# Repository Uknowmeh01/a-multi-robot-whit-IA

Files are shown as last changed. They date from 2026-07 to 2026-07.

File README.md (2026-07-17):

# AI Robot Rover 



A modular, 3D-printable indoor robot rover built around a Raspberry Pi 4 and an ESP32.

The project combines a parametric mechanical chassis, motor control, environmental sensors, a camera, autonomous behaviors, and a local web interface for controlling the robot from a phone or computer.

> [!IMPORTANT]
> The chassis design and software prototype are complete, but the full robot has not yet been physically assembled or tested.

## Project goals

The long-term goal is to build a small indoor assistant robot capable of:

- manual control from a phone;
- autonomous obstacle avoidance;
- camera-based object detection;
- navigation between rooms using visual markers;
- receiving simple voice commands;
- playing sounds or messages through a speaker;
- carrying small objects or messages around the house.

One planned example is telling the robot to go to the living room or to a family member's room. The robot would follow a known route, recognize a visual marker at its destination, stop, and play a notification sound.

## Hardware architecture

The robot uses two main computers:

### Raspberry Pi 4

The Raspberry Pi handles high-level functions:

- camera processing;
- object detection;
- web server and control interface;
- navigation logic;
- communication with the ESP32;
- future voice recognition and audio playback.

### ESP32

The ESP32 handles real-time hardware control:

- four DC motors;
- two TB6612FNG motor drivers;
- ultrasonic distance sensors;
- LEDs;
- environmental sensors;
- emergency stopping;
- serial communication with the Raspberry Pi.

## Planned hardware

- Raspberry Pi 4
- ESP32 development board
- 4 DC geared motors
- 2 TB6612FNG motor drivers
- Raspberry Pi Camera Module 3 Wide
- HC-SR04 ultrasonic sensors
- BH1750 light sensor
- microphone
- LEDs
- battery and power regulation system
- future USB speaker
- 3D-printed mechanical chassis
- M3 screws, nuts, and threaded inserts

Exact motor, battery, and mounting dimensions may still be adjusted to match the purchased hardware.

## Mechanical design

The chassis was designed as a parametric, multi-part KCL project in Zoo Design Studio.

### Main dimensions

| Property | Value |
|---|---:|
| Main deck size | 280 × 200 mm |
| Mechanical stack height | 148 mm |
| Approximate maximum length with angled inserts | 304 mm |
| M3 clearance hole | 3.4 mm |
| Maximum individual print area | 220 × 220 mm |

All individual parts are designed to fit on a standard 220 × 220 mm print bed.

### Mechanical features

- split lower deck for easier printing;
- three alignment tongues between lower-deck sections;
- aligned M3 joint holes;
- removable front and rear panels;
- removable corner brackets;
- reserved mounting areas for motors, battery, and motor drivers;
- cable-routing openings;
- separate sensor and camera inserts;
- modular upper electronics plate;
- removable top cover;
- editable shared parameters;
- exploded and inspection assemblies.

The current model intentionally contains only mechanical geometry and empty mounting provisions. Electronics, motors, wheels, batteries, cameras, sensors, and cables are not modeled as solid components.

## CAD files

The main CAD files include:

```text
cad/
├── main.kcl
├── explodedView.kcl
├── lowerDeckAssembly.kcl
├── parameters.kcl
├── chassisDimensions.md
├── removableCornerBracket.kcl
└── printable-parts/
```

The exact directory structure may differ depending on how the exported Zoo project is organized.

### Main CAD documents

- `main.kcl` contains the complete assembled chassis.
- `explodedView.kcl` contains the exploded assembly.
- `lowerDeckAssembly.kcl` provides a clear view of the split-deck joint.
- `parameters.kcl` contains shared editable dimensions.
- `chassisDimensions.md` documents dimensions, quantities, print envelopes, and export information.

### Printable parts

The project contains separate KCL parts for:

- front lower plate;
- rear lower plate;
- upper electronics plate;
- top cover;
- front sensor panel;
- rear utility panel;
- ultrasonic mounting insert;
- camera mounting insert;
- lower spacer posts;
- upper spacer posts;
- removable corner brackets.

STEP and STL binaries are not currently included because the original design environment exports KCL source files. Each printable part is isolated and ready to be exported from Zoo Design Studio.

## Software

The software is divided between the ESP32 and Raspberry Pi.

```text
software/
├── esp32/
└── raspberry-pi/
```

### ESP32 software

The ESP32 firmware is responsible for:

- motor control;
- serial command parsing;
- ultrasonic sensor measurements;
- lighting control;
- Bluetooth communication;
- autonomous safety behavior.

### Raspberry Pi software

The Raspberry Pi application includes:

- robot control logic;
- camera support;
- object-detection prototype;
- serial communication with the ESP32;
- operating-mode management;
- local web server;
- phone-friendly control interface;
- installation script;
- systemd service;
- tests.

## Web control interface

The Raspberry Pi hosts a local control website.

The interface is intended to provide:

- movement controls;
- speed adjustment;
- operating-mode selection;
- emergency stop;
- sensor information;
- connection status;
- AI detection information.

When the robot is connected to the same Wi-Fi network as a phone or computer, the interface can be opened using the Raspberry Pi's local IP address.

Example:

```text
http://192.168.1.42:5000
```

The exact IP address depends on the local network.

## Operating modes

The planned modes include:

### Manual mode

The user controls movement from the web interface or Bluetooth.

### Autonomous mode

The robot uses its distance sensors to move while avoiding obstacles.

### AI vision mode

The Raspberry Pi camera runs an object-detection prototype. The current software may use a person as its default target, but this behavior can be changed.

### Future navigation mode

A future version will use visual markers such as AprilTags or ArUco markers.

Each room or waypoint can have a unique marker. The robot will use these markers to follow routes and recognize when it has reached a destination.

## Current project status

### Completed

- [x] Parametric chassis design
- [x] Separate printable parts
- [x] Main mechanical assembly
- [x] Exploded assembly
- [x] Split lower-deck system
- [x] Removable corner brackets
- [x] Motor and battery reserved zones
- [x] ESP32 firmware prototype
- [x] Raspberry Pi software prototype
- [x] Local web interface prototype
- [x] Installation script and service files

### Not yet completed

- [ ] Print physical chassis parts
- [ ] Purchase and measure final hardware
- [ ] Assemble the complete rover
- [ ] Test motor direction and speed
- [ ] Test battery and power distribution
- [ ] Validate sensor measurements
- [ ] Validate emergency-stop behavior
- [ ] Test the Raspberry Pi and ESP32 protocol
- [ ] Test the web interface on the physical robot
- [ ] Add visual-marker navigation
- [ ] Add voice commands
- [ ] Add speaker notifications
- [ ] Document real-world test results

## Safety

Initial motor tests should be performed with the wheels raised off the ground.

Before autonomous testing:

- verify the emergency stop;
- use a low movement speed;
- keep cables away from wheels;
- securely mount the battery;
- add suitable power protection and a fuse;
- test in an open indoor area;
- keep the robot away from stairs and fragile objects.

## Repository structure

A possible repository layout is:

```text
AI-Robot-Rover/
├── README.md
├── LICENSE
├── .gitignore
├── docs/
│   └── images/
│       └── chassis-final.png
├── cad/
│   ├── main.kcl
│   ├── explodedView.kcl
│   ├── lowerDeckAssembly.kcl
│   ├── parameters.kcl
│   └── chassisDimensions.md
└── software/
    ├── esp32/
    └── raspberry-pi/
```

## Development notes

Some parts of the initial CAD and software were created with assistance from AI development tools.

All generated work will be reviewed, adapted, physically tested, and documented during the construction process. A generated design passing software validation does not guarantee that every mechanical tolerance or hardware integration detail will work correctly on the first physical build.

## Future ideas

- indoor room-to-room navigation;
- voice activation;
- destination markers;
- speaker announcements;
- automatic charging station;
- motor encoders;
- IMU-assisted movement;
- battery monitoring;
- removable payload platform;
- improved camera mount;
- physical emergency-stop button.

## License

A license has not yet been selected.

Before other people reuse the project, an open-source license such as the MIT License, Apache-2.0, or CERN Open Hardware Licence should be added.

## Author

Created by **Uknowmeh01** as a personal robotics and engineering project.

Built for learning, experimenting, and sharing with the Hack Club community.

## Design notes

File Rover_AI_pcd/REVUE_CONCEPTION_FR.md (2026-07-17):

# Revue de conception et guide de production

## 1. Dimensionnement électrique

Hypothèse de départ : quatre moteurs 6 V, environ 1 A chacun en régime et jusqu'à 3 A au blocage. Le moteur représente ~4 A moyens et 12 A transitoires sur VBAT. Le Raspberry Pi 4 et ses périphériques USB peuvent demander 4 A sur 5 V ; ESP32, capteurs et LED ajoutent environ 0,8 A. À 7,4 V et 90 % de rendement, la charge 5 V/4,8 A demande environ 3,6 A à la batterie. Le courant moyen de pack peut donc approcher 7,6 A, avec des pointes supérieures à 15 A.

Recommandations : pack 2S avec BMS ≥20 A, câbles batterie AWG16, interrupteur et arrêt d'urgence ≥20 A DC, F1 15 A à temporisation adaptée, buck 5 V/9 A. Si les essais au blocage dépassent la capacité des TB6612, ne pas augmenter simplement le fusible : changer les drivers.

## 2. Mesure batterie

L'INA226 est retenu plutôt que l'INA219 : meilleure résolution, plage de bus jusqu'à 36 V, temps de conversion configurable et meilleure marge pour les transitoires. Avec 5 mΩ, 15 A donnent 75 mV et 1,125 W ; le shunt 3 W garde une marge thermique. La calibration logicielle doit utiliser la valeur réellement mesurée du shunt.

## 3. Adaptation HC-SR04

Chaque ECHO passe par 10 kΩ en série puis 20 kΩ vers la masse, soit environ 3,33 V pour une sortie 5 V. Pour une liaison unidirectionnelle lente, ce pont est plus simple et plus robuste qu'un convertisseur bidirectionnel à MOSFET. Les résistances doivent rester près de l'ESP32. TRIG est directement en 3,3 V ; les HC-SR04 usuels le reconnaissent. Si une variante ne le reconnaît pas, ajouter un buffer AHCT.

## 4. Commande des moteurs

Deux 74HC595 génèrent les huit directions et les LED d'état ; les quatre PWM restent directement reliés aux timers ESP32. Au démarrage, maintenir MOTOR_STBY bas, charger les registres, verrouiller les sorties puis seulement activer STBY. Les TB6612FNG intègrent les diodes de roue libre ; des diodes externes ne sont pas nécessaires. C7/C9 et C8/C10 doivent être au plus près des broches VCC/VM, C2 près de la zone puissance, et un 100 nF doit être soudé aux bornes de chaque moteur.

## 5. Implantation et routage

- Carte 4 couches : F.Cu signaux/puissance, In1 signaux horizontaux, In2 signaux verticaux/retours courts, B.Cu plan GND continu.
- Zone forte intensité à gauche, logique au centre, Raspberry Pi et connecteurs capteurs à droite.
- Garder au moins 20 mm entre boucles moteurs/buck et connecteurs capteurs.
- Largeurs après calcul IPC et validation fabricant : batterie/VMOTOR 4 mm sur cuivre externe 2 oz ou polygone équivalent ; chaque moteur ≥2 mm ; 5 V principal ≥2,5 mm ; logique 0,25 mm ; vias puissance multiples 0,4 mm finis minimum.
- Réunir les retours moteur au plan près de C2 et du shunt ; ne pas créer une coupure étroite sous ESP32/INA226.
- Les pistes de mesure IN+/IN− doivent être Kelvin jusqu'aux pads internes du shunt et éloignées des sorties moteur.

Le PCB fourni contient un pré-routage en grille et deux plans GND. Avant fabrication, inspecter les croisements, retoucher les pistes de puissance en polygones, ajouter les vias de couture et relancer le DRC avec les règles du fabricant.

## 6. Fabrication JLCPCB / PCBWay

- 4 couches, FR-4 TG150, 1,6 mm, cuivre externe 2 oz et interne 1 oz.
- Finition ENIG recommandée pour le shunt et les petits boîtiers ; HASL sans plomb acceptable pour un prototype manuel.
- Espacement/piste logique ≥0,20 mm, idéal 0,25 mm.
- Via fini 0,40 mm / diamètre 0,80 mm ; trous connecteurs 0,9 à 1,3 mm selon pièce ; montage 2,7 mm pour vis M2.5.
- Masque épargne des deux côtés, sérigraphie blanche, contrôle d'impédance inutile.
- Commander d'abord 5 cartes, assembler une seule carte et terminer les essais avant le lot.

## 7. Assemblage

1. Contrôler PCB nu à l'ohmmètre : aucune continuité VBAT/GND, 5V/GND ou 3V3/GND.
2. Monter passifs, INA226, 74HC595, AP2112 et TB6612 ; inspecter les ponts sous loupe.
3. Monter protections et buck, sans Raspberry Pi, ESP32, capteurs ni moteurs.
4. Mettre une alimentation de laboratoire à 7,4 V, limite 100 mA ; vérifier polarité et absence d'échauffement.
5. Régler/vérifier le buck à 5,10 V. Vérifier 3,3 V.
6. Tester l'I2C et les registres avec l'ESP32 seul, puis brancher le Pi.
7. Tester un moteur roue levée avec limite de courant, puis quatre moteurs.
8. Tester l'arrêt d'urgence en charge et vérifier que MOTOR_STBY revient bas au redémarrage.

## 8. Procédure de mise sous tension initiale

- Interrupteur ouvert, arrêt d'urgence enclenché, aucun moteur.
- Vérifier résistance vers GND de chaque rail.
- Alimentation de laboratoire 7,4 V limitée à 0,1 A, puis 0,5 A.
- Mesurer VMOTOR, +5V, +5V_RPI, +5V_LOGIC, +3V3 aux TP.
- Contrôler consommation à vide et température pendant 5 minutes.
- Insérer ESP32, charger un firmware minimal avec STBY=0.
- Valider LED, INA226, BH1750 et trois ECHO.
- Insérer le Raspberry Pi éteint, puis augmenter progressivement la limite.

## 9. Checklist de débogage

- Reset ESP32 au démarrage moteur : vérifier chute VBAT, C2, câblage en étoile et masse.
- Pi sous-tension : mesurer +5V_RPI au connecteur J5 sous charge ; viser 5,0–5,1 V sans dépasser 5,25 V.
- Valeur INA226 incorrecte : vérifier routage Kelvin, signe IN+/IN−, valeur du shunt et calibration.
- Distance HC-SR04 erratique : vérifier 5 V, ponts 10k/20k, masse, temporisation et éloignement des pistes PWM.
- Moteur inversé : permuter le bornier ou le mapping logiciel, jamais le shunt.
- LED WS2812 instable : masse commune, buffer AHCT, résistance 330 Ω et condensateur local.

## 10. Améliorations possibles

- Drivers DRV8873 avec mesure de courant et protections intégrées pour moteurs plus puissants.
- Deuxième convertisseur 5 V dédié au Raspberry Pi pour isoler davantage les transitoires.
- Superviseur d'alimentation et arrêt propre du Pi avant coupure batterie.
- Connecteurs verrouillables Micro-Fit pour puissance et JST-GH pour capteurs soumis aux vibrations.
- CAN ou RS-485 pour extensions longues.
- Entrées encodeurs avec filtrage Schmitt et protection ESD.
- Chargeur/BMS intégré uniquement dans une révision séparée, avec étude thermique et conformité batterie.

## 11. Erreurs courantes à éviter

- Utiliser une batterie 3S directement avec des moteurs 6 V sans limitation PWM sûre.
- Choisir les TB6612 sans mesurer le courant de blocage.
- Alimenter le Pi par sa broche 5 V avec un buck mal réglé.
- Relier deux sources 3,3 V ensemble : RPI_3V3 n'est pas relié au +3V3 de la carte.
- Monter plusieurs pull-up I2C en parallèle jusqu'à obtenir une résistance trop faible.
- Faire passer CSI, ECHO ou I2C à côté des sorties moteurs.
- Oublier que le microphone et le haut-parleur USB consomment sur le budget 5 V du Pi.

## 12. Checklist finale de production

- [ ] Courant de blocage moteurs mesuré et compatible.
- [ ] Pinout ESP32 réel comparé au PCB.
- [ ] Empreintes comparées aux datasheets et modèles 1:1 imprimés.
- [ ] ERC sans erreur non justifiée.
- [ ] DRC sans violation non justifiée.
- [ ] Zones remplies, aucun îlot cuivre, vias de couture ajoutés.
- [ ] Pistes Kelvin INA226 vérifiées.
- [ ] Polarités J1, condensateurs, diodes et LED vérifiées.
- [ ] Buck réglé à 5,10 V et testé à 6 A.
- [ ] Test arrêt d'urgence et fusible effectué.
- [ ] Gerbers, perçages, IPC-356, BOM et plan d'assemblage relus.
- [ ] Une carte prototype validée thermiquement avant série.

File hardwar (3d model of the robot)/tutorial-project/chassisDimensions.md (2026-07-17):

# Chassis engineering update

## Added in revision

1. Added editable hardware-fit parameters in `parameters.kcl` for motor reserves, battery reserve/access opening, driver reserves, M3 nut-relief diameter/depth, and corner-bracket geometry.
2. Added `removableCornerBracket.kcl` with four printable removable L-brackets. Brackets include M3 clearance holes and cylindrical nut-relief counterbores for captured hardware access.
3. Added four bracket instances to `main.kcl` for removable front/rear and side panel support.

## Hardware-fit tuning parameters

- Motor reserve: 46 x 36 mm
- Motor hole spacing: 32 x 24 mm
- Battery reserve: 70 x 72 mm
- Battery access opening: 42 x 52 mm
- Driver reserve: 36 x 22 mm
- M3 clearance: 3.4 mm
- Nut-relief diameter/depth: 6.6 / 2.4 mm

These are editable envelope values, not modeled electronic or motor geometry. Tune them against the selected purchased hardware before fabrication.

## Validation

- `main.kcl` mock execution: passed
- Corner-bracket constraint check: passed
- Lint: passed
- Individual printable parts remain separate; no glue-dependent assembly was introduced.

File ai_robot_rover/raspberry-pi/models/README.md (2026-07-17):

# Modèle IA

`install.sh` télécharge automatiquement `efficientdet_lite0.tflite` depuis le stockage public MediaPipe si le fichier est absent. Le modèle INT8 reconnaît les 80 classes COCO listées dans `coco_labels.txt`.

Pour remplacer le modèle, modifiez `MODEL_PATH`, `LABELS_PATH` et, si nécessaire, `AI_CONFIDENCE_THRESHOLD` dans `config.py`. Le détecteur accepte les sorties TFLite usuelles `boxes`, `classes`, `scores` et `count`.

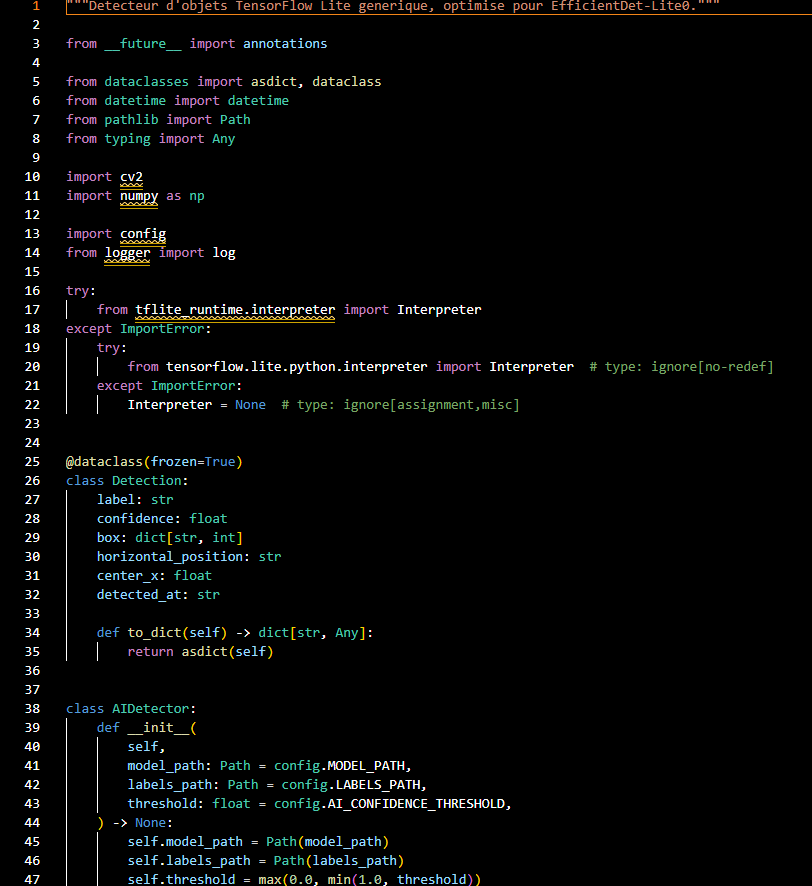
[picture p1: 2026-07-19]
asset/Screenshot 2026-07-17 164706.png

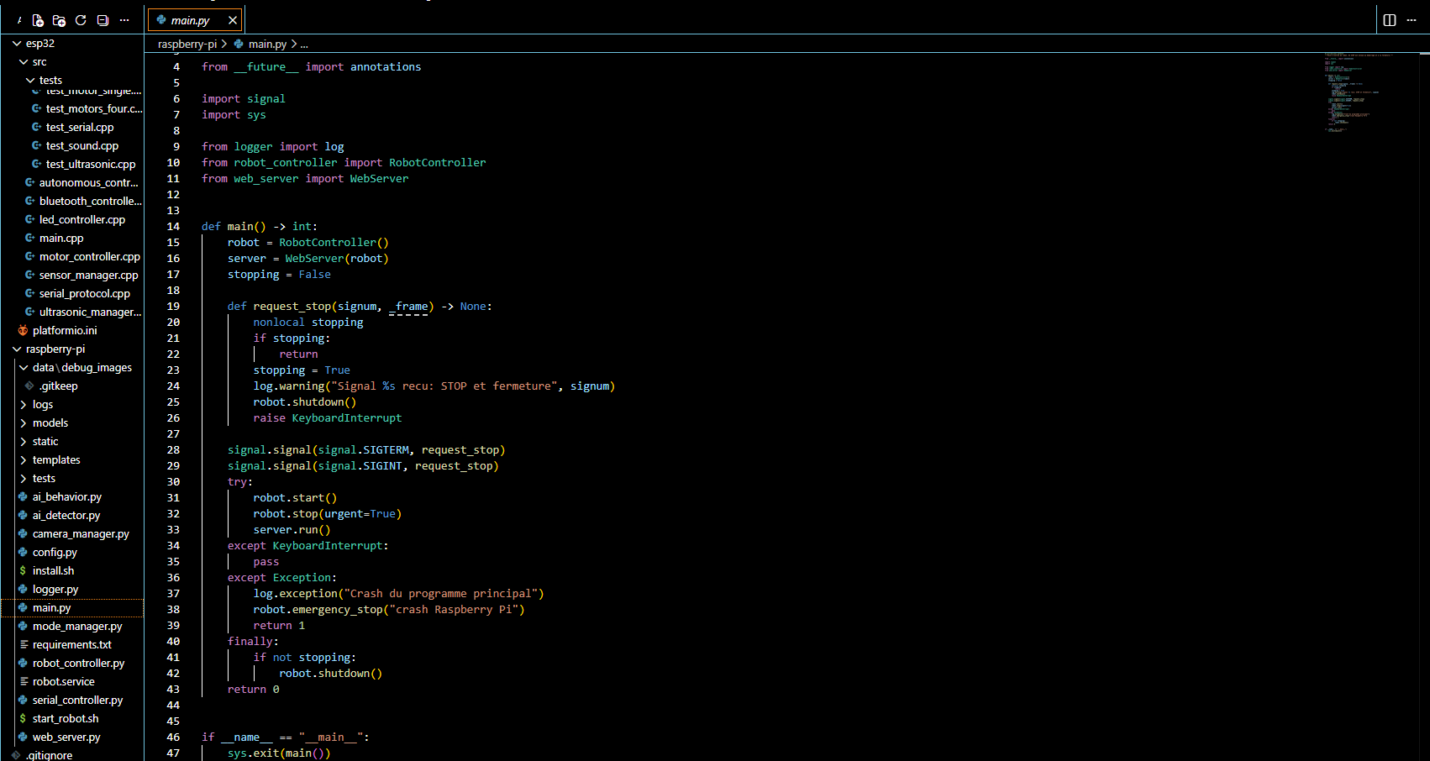
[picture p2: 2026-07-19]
asset/Screenshot 2026-07-19 124222.png

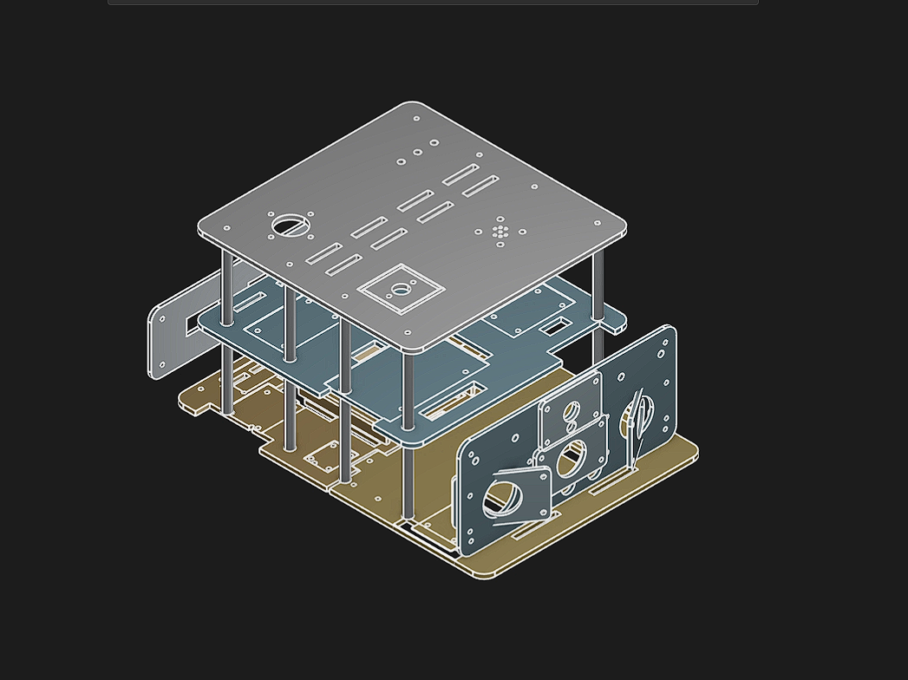
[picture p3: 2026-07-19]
asset/623308507-7109efb7-1d62-4a83-8e4f-e09f7bfac228.png

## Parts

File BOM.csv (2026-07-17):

Category | Item | Quantity | Recommended specification | Priority | Notes
---------- | ------------------------------------------ | -----------: | -------------------------------------------------- | ---------------------- | -------------------------------------------------------
Computing | Raspberry Pi 4 | 1 | 4 GB RAM model | Required | Handles camera, web interface, AI, navigation and audio
Computing | ESP32 development board | 1 | ESP32-WROOM-32 DevKit | Required | Handles motors, sensors, LEDs and real-time control
Computing | MicroSD card | 1 | 32 or 64 GB, A1 or A2 | Required | Raspberry Pi operating system and software
Computing | USB cable | 1 | Compatible with the ESP32 connector | Required | Communication between Raspberry Pi and ESP32
Cooling | Raspberry Pi heatsink kit | 1 | Compatible with Raspberry Pi 4 | Recommended | Helps control temperature
Cooling | Cooling fan | 1 | 30 mm or 40 mm | Recommended | Match the chassis mounting area
Motion | DC geared motors | 4 | Preferably with built-in encoders | Required | Check voltage, current, shaft size and dimensions
Motion | Wheels | 4 | Compatible with motor shafts | Required | Choose suitable diameter and grip
Motion | TB6612FNG motor drivers | 2 | Dual-channel motor driver boards | Required | One board controls two motors
Motion | Motor brackets | 4 | Metal or 3D-printed | Required | Must match the exact motors
Motion | Motor mounting hardware | 1 set | Screws, washers and nuts | Required | Size depends on the motor brackets
Power | Protected battery pack | 1 | Pre-assembled pack with protection/BMS | Required | Do not build a lithium pack from loose cells
Power | Battery charger | 1 | Exact match for battery chemistry and voltage | Required | Must be compatible with the selected battery
Power | Raspberry Pi DC-DC converter | 1 | Stable 5 V output, at least 3 A | Required | Powers the Raspberry Pi safely
Power | Motor DC-DC converter | 1 | Only if motor voltage differs from battery voltage | Conditional | Choose after selecting motors and battery
Power | Main power switch | 1 | Rated for the robot’s maximum current | Required | Must be easily accessible
Power | Emergency-stop button | 1 | Latching type | Strongly recommended | Should immediately disable motor power
Power | Fuse holder | 1 | Inline or panel-mounted | Required | Place close to the battery
Power | Fuses | Several | Value selected after motor current is known | Required | Keep spare fuses
Power | Power distribution board or terminal block | 1 | Rated for total current | Required | Distributes battery power safely
Power | Battery connectors | 1 pair | Polarized, locking connectors | Required | Prevents reversed connections
Power | Battery monitoring sensor | 1 | INA219 or INA226 | Recommended | Measures voltage and current
Sensors | Ultrasonic distance sensors | 3 | HC-SR04 or 3.3 V-compatible equivalent | Required | Front, left and right
Sensors | Logic-level converter | 1 | At least 3 channels | Required with HC-SR04 | Protects ESP32 inputs from 5 V Echo signals
Sensors | Light sensor | 1 | BH1750 | Required | Measures ambient light
Sensors | IMU | 1 | MPU6050, BNO055 or equivalent | Recommended | Helps estimate orientation and movement
Sensors | Motor encoders | 4 | Built into motors if possible | Recommended | Improves navigation accuracy
Sensors | Cliff sensors | 2 to 4 | Infrared downward-facing sensors | Recommended | Helps avoid stairs and drops
Sensors | Limit switches | 2 | Small lever-type switches | Optional | Can detect physical contact
Vision | Raspberry Pi Camera Module 3 Wide | 1 | Wide-angle version | Required for AI vision | Used for object and marker detection
Vision | CSI camera ribbon cable | 1 | Correct length for the chassis | Required | Connects the camera to the Raspberry Pi
Vision | Adjustable camera mount | 1 | 3D-printed | Required | Should allow vertical angle adjustment
Navigation | AprilTags or ArUco markers | Several | Printed on matte paper or card | Future feature | Used for room and waypoint navigation
Audio | USB microphone | 1 | Linux-compatible | Future feature | Simplest option for voice commands
Audio | USB speaker | 1 | Compact, Raspberry Pi-compatible | Future feature | Used for sounds and spoken messages
Audio | Small amplifier and speaker | 1 set | Alternative to USB speaker | Optional | Requires additional wiring
Audio | Buzzer | 1 | 3.3 V or transistor-driven | Recommended | Simple alerts and status sounds
Lighting | Status LEDs | 3 to 5 | Different colors | Recommended | Power, error, mode and connection indicators
Lighting | LED resistors | 1 set | Values matched to selected LEDs | Required with LEDs | Protects LEDs and GPIO pins
Lighting | LED strip or LED ring | 1 | 5 V addressable type | Optional | Visual robot status effects
Wiring | Flexible electrical wire | 1 assortment | Multiple gauges | Required | Thicker wire for motors and battery
Wiring | Dupont jumper wires | 1 set | Male and female assortment | Prototyping only | Avoid for motor or battery power
Wiring | JST connector kit | 1 assortment | Matching crimp terminals and housings | Recommended | Makes wiring removable and tidy
Wiring | Screw terminals | Several | Rated for expected current | Recommended | Useful for motors and power distribution
Wiring | Heat-shrink tubing | 1 assortment | Multiple diameters | Required | Insulates soldered connections
Wiring | Cable ties | 1 pack | Small sizes | Required | Cable management
Wiring | Cable-tie mounts | Several | Adhesive or screw-mounted | Optional | Helps organize the chassis
Wiring | Perfboard or custom distribution PCB | 1 | Suitable size | Recommended | Better than a breadboard for final assembly
Wiring | Breadboard | 1 | Standard solderless board | Prototyping only | Use only during early testing
Wiring | Ferrules | 1 assortment | Match wire sizes | Recommended | Improves screw-terminal connections
Wiring | Electrical tape | 1 roll | Quality insulation tape | Recommended | Supplementary insulation only
Chassis | PETG filament | 1 to 2 kg | 1.75 mm | Required | Better heat and impact resistance than basic PLA
Chassis | M3 screws | 1 assortment | Several lengths | Required | Used throughout the chassis
Chassis | M3 DIN 934 hex nuts | 1 assortment | Standard steel nuts | Required | Compatible with captive nut pockets
Chassis | M3 washers | 1 assortment | Standard flat washers | Recommended | Spreads mechanical load
Chassis | M3 lock nuts | Several | Nylon-insert type | Recommended | Useful in vibrating areas
Chassis | M3 heat-set inserts | 30 to 60 | Match printed pocket dimensions | Recommended | Allows repeated assembly
Chassis | M2.5 or M3 standoffs | 1 set | Plastic or metal | Required | Mounts the Raspberry Pi and electronics
Chassis | Velcro straps | 2 to 3 | Reusable | Required | Battery and cable retention
Chassis | Rubber pads | Several | Small adhesive pads | Optional | Reduces vibration
Chassis | Fan guard | 1 | Match fan size | Recommended | Protects fingers and cables
Tools | Multimeter | 1 | Digital | Required | Essential for electrical testing
Tools | Screwdriver set | 1 | Small electronics sizes | Required | Assembly and maintenance
Tools | Caliper | 1 | Digital or mechanical | Recommended | Checks printed dimensions and hardware fit
Tools | Soldering iron | 1 | Temperature-controlled | Required | Permanent electrical connections
Tools | Soldering-iron stand | 1 | Heat-resistant | Required | Safer soldering
Tools | Desoldering braid or pump | 1 | Standard electronics type | Recommended | Fixes soldering mistakes
Tools | Helping hands | 1 | Adjustable clips | Recommended | Holds wires while soldering
Tools | Wire cutters | 1 | Small electronics type | Required | Cuts wires and leads
Tools | Wire stripper | 1 | Suitable for selected wire gauges | Required | Prepares electrical wires
Tools | JST crimping tool | 1 | Compatible with selected terminals | Recommended | Makes reliable connectors
Tools | Safety glasses | 1 | Impact-resistant | Required | For soldering and assembly
Tools | USB power meter | 1 | USB voltage/current display | Optional | Useful for Raspberry Pi power testing

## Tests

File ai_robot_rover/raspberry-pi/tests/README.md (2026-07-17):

# Programmes de test Raspberry Pi

Exécuter depuis `raspberry-pi` avec l'environnement installé :

```bash
.venv/bin/python tests/test_serial_communication.py
.venv/bin/python tests/test_camera.py
.venv/bin/python tests/test_ai_model.py
.venv/bin/python tests/test_ai_model.py chemin/vers/image.jpg
.venv/bin/python tests/test_web_interface.py
.venv/bin/python tests/test_emergency_stop.py --confirm-wheels-off-ground
```

Le test Web ne déplace aucun moteur. Les tests série commencent et terminent par `STOP`. Ne réarmez jamais un arrêt d'urgence avant d'avoir retiré l'obstacle et identifié sa cause.

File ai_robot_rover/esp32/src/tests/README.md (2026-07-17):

# Tests matériels ESP32

Chaque fichier est un programme PlatformIO indépendant sélectionné par un environnement de `platformio.ini`.

```bash
pio run -e test_motor_single -t upload
pio run -e test_motors_four -t upload
pio run -e test_ultrasonic -t upload
pio run -e test_bh1750 -t upload
pio run -e test_sound -t upload
pio run -e test_leds -t upload
pio run -e test_bluetooth -t upload
pio run -e test_serial -t upload
pio run -e test_emergency -t upload
pio device monitor -b 115200
```

Les tests moteur et arrêt d'urgence exigent le mot `START` sur le moniteur série. Retirer les roues du sol, dégager les câbles, prévoir un interrupteur physique sur l'alimentation moteur et commencer avec `MIN_TEST_SPEED` dans `include/config.h`.

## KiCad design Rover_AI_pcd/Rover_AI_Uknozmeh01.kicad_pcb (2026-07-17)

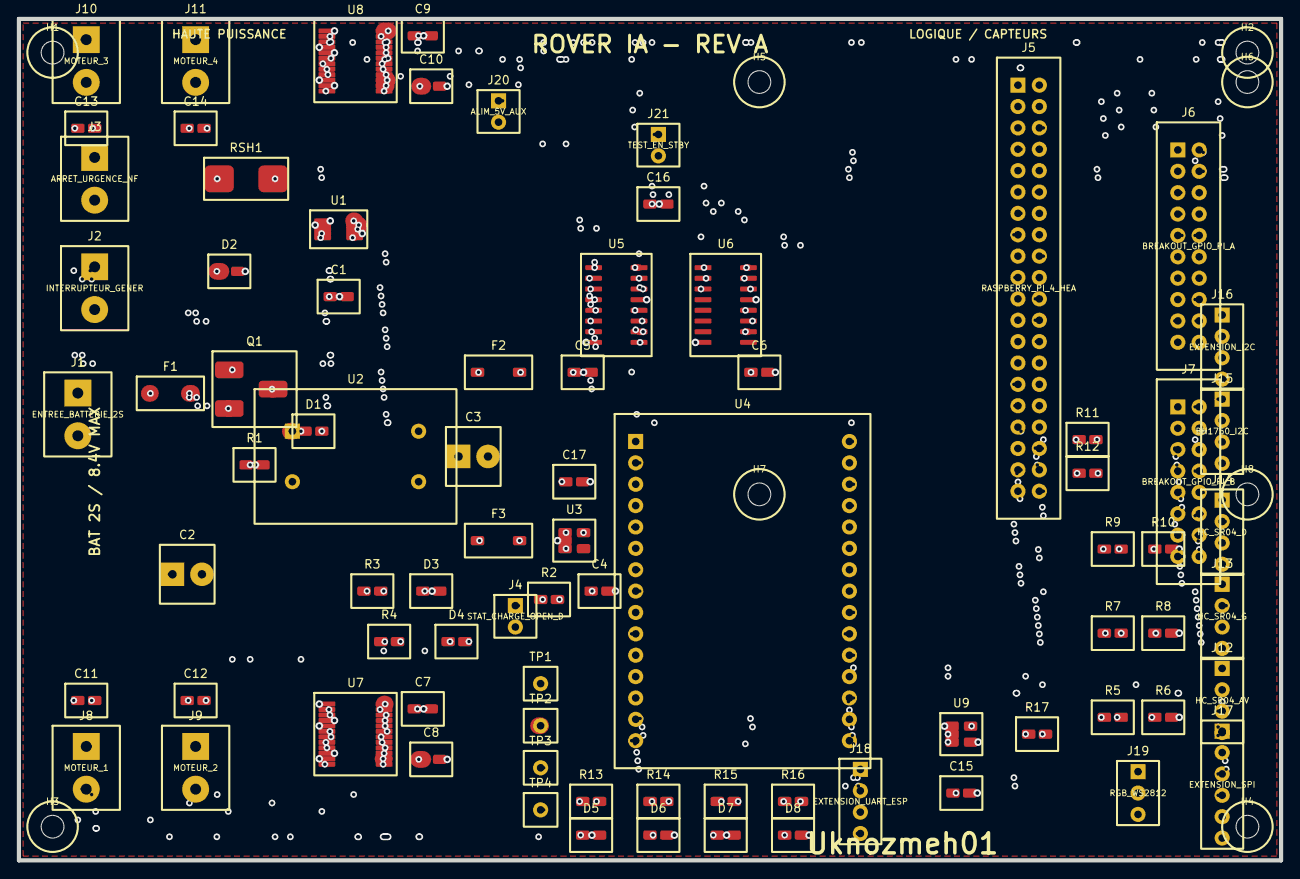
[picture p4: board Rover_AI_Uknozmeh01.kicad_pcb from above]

Board: 4 copper layers, 150.0 x 100.0 mm, 89 parts (0 on the bottom side), 96 nets.

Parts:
C1, C5, C6, C7, C9, C15, C16: 100n; c
C2: 1000u_16V_lowESR; cap_big
C3: 470u_10V_lowESR; cap_big
C4: 1u; c
C8, C10: 10u_16V; c
C11, C12, C13, C14: 100n_MOTEUR; c
C17: 10u; c
D1: BZT52C10; d
D2: SMBJ9.0A; d
D3: LED_VERTE_POWER; led
D4: LED_ORANGE_CHARGE; led
D5: LED_BLEUE_ESP; led
D6: LED_VIOLETTE_AI; led
D7: LED_VERTE_AUTO; led
D8: LED_JAUNE_USER; led
F1: FUSIBLE_15A; fuse
F2: PTC_5A; fuse
F3: PTC_1.5A; fuse
H1, H2, H3, H4, H5, H6, H7, H8: MountingHole_2.7
J1: ENTREE_BATTERIE_2S; terminal2
J2: INTERRUPTEUR_GENERAL; terminal2
J3: ARRET_URGENCE_NF; terminal2
J4: STAT_CHARGE_OPEN_DRAIN; connector2
J5: RASPBERRY_PI_4_HEADER_40P; header2x20
J6: BREAKOUT_GPIO_PI_A; header2x10
J7: BREAKOUT_GPIO_PI_B; header2x8
J8: MOTEUR_1; terminal2
J9: MOTEUR_2; terminal2
J10: MOTEUR_3; terminal2
J11: MOTEUR_4; terminal2
J12: HC_SR04_AV; connector4
J13: HC_SR04_G; connector4
J14: HC_SR04_D; connector4
J15: BH1750_I2C; connector4
J16: EXTENSION_I2C; connector4
J17: EXTENSION_SPI; connector6
J18: EXTENSION_UART_ESP; connector4
J19: RGB_WS2812; connector3
J20: ALIM_5V_AUX; connector2
J21: TEST_EN_STBY; connector2
Q1: IPD90P03P4L-04; dpak
R1, R2: 100k; r
R3, R4, R13, R14, R15, R16: 1k; r
R5, R7, R9: 10k; r
R6, R8, R10: 20k; r
R11, R12: 4k7_DNP; r
R17: 330R; r
RSH1: 5mR_3W_1%; shunt
TP1: TP_GND; testpoint
TP2: TP_VMOTOR; testpoint
TP3: TP_5V; testpoint
TP4: TP_3V3; testpoint
U1: INA226AIDGSR; vssop10
U2: BUCK_5V_9A_D24V90F5; module4
U3: AP2112K-3.3; sot23_5
U4: ESP32_DEVKIT_V1_30P; module2x15
U5: 74HC595D_MOTEURS; soic16
U6: 74HC595D_LED; soic16
U7: TB6612FNG_M1_M2; ssop24
U8: TB6612FNG_M3_M4; ssop24
U9: SN74AHCT1G125; sot23_5

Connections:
+3V3: C1.1, C4.1, C5.1, C6.1, C7.1, C9.1, C16.1, J7.14, J15.1, J16.1, J17.1, J18.1, R11.1, R12.1, TP4.1, U1.6, U3.5, U4.30, U5.10, U5.16, U6.10, U6.16, U7.20, U8.20
+5V: C3.1, F2.1, F3.1, TP3.1, U2.3
+5V_LOGIC: C15.1, C17.1, F3.2, J7.15, J12.1, J13.1, J14.1, J19.1, J20.1, R2.2, R3.1, R4.1, U3.1, U4.15, U9.5
+5V_RPI: F2.2, J5.2, J5.4
CHG_LED_A: D4.1, R4.2
CHG_STAT: D4.2, J4.1
ECHO_AV: R5.2, R6.1, U4.2
ECHO_AV_5V: J12.3, R5.1
ECHO_D: R9.2, R10.1, U4.5
ECHO_D_5V: J14.3, R9.1
ECHO_G: R7.2, R8.1, U4.4
ECHO_G_5V: J13.3, R7.1
EN_3V3: R2.1, U3.3
ESP_RX0: J7.13, U4.19
ESP_TX0: J7.12, U4.18
GND: C1.2, C2.2, C3.2, C4.2, C5.2, C6.2, C7.2, C8.2, C9.2, C10.2, C15.2, C16.2, C17.2, D2.2, D3.2, D5.2, D6.2, D7.2, D8.2, J1.2, J4.2, J5.6, J5.9, J5.14, J5.20, J5.25, J5.30, J5.34, J5.39, J6.2, J6.20, J7.2, J7.16, J12.4, J13.4, J14.4, J15.2, J16.2, J17.2, J18.2, J19.3, J20.2, J21.2, R1.2, R6.2, R8.2, R10.2, TP1.1, U1.1, U1.2, U1.7, U2.2, U2.4, U3.2, U4.14, U4.21, U5.8, U5.13, U6.8, U6.13, U7.1, U7.4, U7.5, U7.10, U7.11, U8.1, U8.4, U8.5, U8.10, U8.11, U9.1, U9.4
I2C_SCL: J15.3, J16.3, R11.2, U1.5, U4.17
I2C_SDA: J15.4, J16.4, R12.2, U1.4, U4.20
LED_AI_A: R14.1, U6.1
LED_AI_A_R: D6.1, R14.2
LED_AUTO_A: R15.1, U6.2
LED_AUTO_A_R: D7.1, R15.2
LED_ESP_A: R13.1, U6.15
LED_ESP_A_R: D5.1, R13.2
LED_USER_A: R16.1, U6.3
LED_USER_A_R: D8.1, R16.2
M1_IN1: U5.15, U7.21
M1_IN2: U5.1, U7.22
M1_O1: C11.1, J8.1, U7.2, U7.3
M1_O2: C11.2, J8.2, U7.6, U7.7
M1_PWM: U4.8, U7.23
M2_IN1: U5.2, U7.18
M2_IN2: U5.3, U7.17
M2_O1: C12.1, J9.1, U7.12, U7.13
M2_O2: C12.2, J9.2, U7.8, U7.9
M2_PWM: U4.9, U7.16
M3_IN1: U5.4, U8.21
M3_IN2: U5.5, U8.22
M3_O1: C13.1, J10.1, U8.2, U8.3
M3_O2: C13.2, J10.2, U8.6, U8.7
M3_PWM: U4.10, U8.23
M4_IN1: U5.6, U8.18
M4_IN2: U5.7, U8.17
M4_O1: C14.1, J11.1, U8.12, U8.13
M4_O2: C14.2, J11.2, U8.8, U8.9
M4_PWM: U4.11, U8.16
MOTOR_STBY: J21.1, U4.27, U7.19, U8.19
PI_GPIO2: J5.3, J6.3
PI_GPIO3: J5.5, J6.4
PI_GPIO4: J5.7, J6.5
PI_GPIO5: J5.29, J6.18
PI_GPIO6: J5.31, J6.19
PI_GPIO7: J5.26, J6.17
PI_GPIO8: J5.24, J6.16
PI_GPIO9: J5.21, J6.13
PI_GPIO10: J5.19, J6.12
PI_GPIO11: J5.23, J6.15
PI_GPIO12: J5.32, J7.3
PI_GPIO13: J5.33, J7.4
PI_GPIO16: J5.36, J7.6
PI_GPIO17: J5.11, J6.6
PI_GPIO18: J5.12, J6.7
PI_GPIO19: J5.35, J7.5
PI_GPIO20: J5.38, J7.8
PI_GPIO21: J5.40, J7.9
PI_GPIO22: J5.15, J6.9
PI_GPIO23: J5.16, J6.10
PI_GPIO24: J5.18, J6.11
PI_GPIO25: J5.22, J6.14
PI_GPIO26: J5.37, J7.7
PI_GPIO27: J5.13, J6.8
PI_ID_SC: J5.28, J7.11
PI_ID_SD: J5.27, J7.10
PWR_LED_K: D3.1, R3.2
Q_GATE: D1.1, Q1.1, R1.1
RGB_DATA_3V3: U4.28, U9.2
RGB_DATA_5V: R17.1, U9.3
RGB_DATA_OUT: J19.2, R17.2
RPI_3V3: J5.1, J5.17, J6.1, J7.1
SPI_CS: J17.6, U4.29
SPI_MISO: J17.5, U4.22
SR_CHAIN: U5.9, U6.14
SR_CLK: J17.3, U4.23, U5.11, U6.11
SR_DATA: J17.4, U4.16, U5.14
SR_LATCH: U4.24, U5.12, U6.12
TRIG_AV: J12.2, U4.6
TRIG_D: J14.2, U4.13
TRIG_G: J13.2, U4.7
UART_RX_ESP: J5.8, J18.4, U4.26
UART_TX_ESP: J5.10, J18.3, U4.25
VBAT_ESTOP: J3.2, RSH1.1, U1.10
VBAT_FUSED: F1.2, Q1.3
VBAT_PROTECTED: D1.2, J2.1, Q1.2
VBAT_RAW: F1.1, J1.1
VBAT_SW: J2.2, J3.1
VMOTOR: C2.1, C8.1, C10.1, D2.1, RSH1.2, TP2.1, U1.8, U1.9, U2.1, U7.14, U7.15, U7.24, U8.14, U8.15, U8.24

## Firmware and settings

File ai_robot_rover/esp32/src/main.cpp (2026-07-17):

#include <Arduino.h>

#include "autonomous_controller.h"
#include "bluetooth_controller.h"
#include "config.h"
#include "led_controller.h"
#include "motor_controller.h"
#include "robot_types.h"
#include "sensor_manager.h"
#include "serial_protocol.h"
#include "ultrasonic_manager.h"

MotorController motors;
UltrasonicManager ultrasonics;
SensorManager sensors;
LedController leds;
SerialProtocol serialProtocol(Serial);
BluetoothController bluetooth;
AutonomousController autonomous(motors);

RobotMode currentMode = RobotMode::MANUAL;
uint8_t currentSpeed = Config::DEFAULT_SPEED;
bool emergencyLatched = false;
bool serialTimedOut = false;
bool bluetoothWasConnected = false;
bool sensorFaultWasActive = false;
uint32_t lastMotionCommandMs = 0;
uint32_t lastTelemetryMs = 0;
uint32_t lastStatusMs = 0;

void publishStatus() {
  const auto& d = ultrasonics.readings();
  const auto& s = sensors.readings();
  serialProtocol.sendLine(String("STATUS,MODE=") + modeName(currentMode) +
                          ",SPEED=" + currentSpeed +
                          ",MOVING=" + (motors.isMoving() ? "1" : "0") +
                          ",EMERGENCY=" + (emergencyLatched ? "1" : "0") +
                          ",AUTO_STATE=" + autonomous.stateName());
  if (bluetooth.connected()) {
    bluetooth.sendLine(String("MODE=") + modeName(currentMode) +
                       ", SPEED=" + currentSpeed +
                       ", EMERGENCY=" + (emergencyLatched ? "YES" : "NO") +
                       ", L/C/R=" + String(d.left, 1) + "/" + String(d.center, 1) + "/" + String(d.right, 1) +
                       ", LUX=" + String(s.lightLux, 1) + ", SOUND=" + String(static_cast<int>(s.soundAverage)));
  }
}

void changeMode(RobotMode newMode, CommandSource source) {
  motors.stopAll(true);
  autonomous.stop();
  serialProtocol.clearInput();
  bluetooth.clearInput();
  currentMode = newMode;
  leds.setMode(currentMode);
  lastMotionCommandMs = millis();
  if (currentMode == RobotMode::AUTONOMOUS && !emergencyLatched) autonomous.start();
  serialProtocol.sendLine(String("MODE,") + modeName(currentMode));
  if (bluetooth.connected()) bluetooth.sendLine(String("MODE,") + modeName(currentMode));
  serialProtocol.sendLine(String("EVENT,MODE_CHANGED,") +
                          (source == CommandSource::SERIAL_LINK ? "SERIAL" : "BLUETOOTH"));
}

bool sourceCanMove(CommandSource source) {
  if (source == CommandSource::BLUETOOTH_LINK) return currentMode == RobotMode::BLUETOOTH;
  return currentMode == RobotMode::MANUAL || currentMode == RobotMode::AI;
}

void latchEmergency(const String& reason) {
  if (emergencyLatched) return;
  emergencyLatched = true;
  motors.emergencyStop();
  autonomous.emergencyStop();
  leds.setEmergency(true);
  serialProtocol.sendLine(String("EMERGENCY_STOP,") + reason);
  bluetooth.sendLine(String("EMERGENCY_STOP,") + reason);
}

void handleCommand(const ParsedCommand& command) {
  if (command.type == CommandType::INVALID) {
    if (command.source == CommandSource::SERIAL_LINK) serialProtocol.sendError(command.error);
    else bluetooth.sendLine(String("ERROR,") + command.error);
    return;
  }
  if (command.type == CommandType::EMERGENCY_STOP) {
    latchEmergency(command.source == CommandSource::SERIAL_LINK ? "SERIAL_COMMAND" : "BLUETOOTH_COMMAND");
    return;
  }
  if (command.type == CommandType::CLEAR_EMERGENCY) {
    const auto& distances = ultrasonics.readings();
    const bool distancesValid = distances.leftHealthy && distances.centerHealthy && distances.rightHealthy &&
                                isfinite(distances.left) && isfinite(distances.center) && isfinite(distances.right);
    if (!distancesValid || ultrasonics.emergencyObstacle()) {
      const char* error = distancesValid ? "OBSTACLE_TOO_CLOSE" : "SENSOR_UNAVAILABLE";
      if (command.source == CommandSource::SERIAL_LINK) serialProtocol.sendError(error);
      else bluetooth.sendLine(String("ERROR,") + error);
      return;
    }
    emergencyLatched = false;
    motors.stopAll(true);
    leds.setEmergency(false);
    changeMode(RobotMode::MANUAL, command.source);
    serialProtocol.sendLine("EMERGENCY_CLEARED");
    bluetooth.sendLine("EMERGENCY_CLEARED");
    return;
  }
  if (command.type == CommandType::STATUS) { publishStatus(); return; }
  if (command.type == CommandType::HELP) { bluetooth.sendHelp(); return; }
  if (command.type == CommandType::STOP) {
    motors.stopAll(true);
    lastMotionCommandMs = millis();
    return;
  }
  if (emergencyLatched) {
    if (command.source == CommandSource::SERIAL_LINK) serialProtocol.sendError("EMERGENCY_LATCHED");
    else bluetooth.sendLine("ERROR,EMERGENCY_LATCHED");
    return;
  }
  if (command.type == CommandType::SET_MODE) {
    changeMode(command.mode, command.source);
  } else if (command.type == CommandType::SET_SPEED) {
    currentSpeed = min(command.speed, Config::MAX_SPEED);
    serialProtocol.sendLine(String("SPEED,") + currentSpeed);
  } else if (command.type == CommandType::SET_LED) {
    leds.setUserEnabled(command.enabled);
    serialProtocol.sendLine(String("LED,") + (command.enabled ? "ON" : "OFF"));
  } else if (command.type == CommandType::MOVE) {
    if (!sourceCanMove(command.source)) {
      if (command.source == CommandSource::SERIAL_LINK) serialProtocol.sendError("SOURCE_NOT_OWNER");
      else bluetooth.sendLine("ERROR,SOURCE_NOT_OWNER; SEND M0 FIRST");
      return;
    }
    const uint8_t speed = command.source == CommandSource::BLUETOOTH_LINK
                              ? currentSpeed
                              : min(command.speed, Config::MAX_SPEED);
    motors.setMotion(command.motion, speed);
    lastMotionCommandMs = millis();
  }
}

void publishTelemetry() {
  const auto& d = ultrasonics.readings();
  const auto& s = sensors.readings();
  serialProtocol.sendDistance("LEFT", d.left);
  serialProtocol.sendDistance("CENTER", d.center);
  serialProtocol.sendDistance("RIGHT", d.right);
  if (isfinite(s.lightLux)) Serial.printf("LIGHT,%.1f\n", s.lightLux);
  Serial.printf("SOUND,%u\n", static_cast<unsigned>(s.soundAverage));
  if (ultrasonics.closeObstacle()) serialProtocol.sendLine("OBSTACLE,CENTER");
}

void setup() {
  Serial.begin(Config::SERIAL_BAUD);
  motors.begin();
  ultrasonics.begin();
  sensors.begin();
  leds.begin();
  leds.setMode(currentMode);
  const bool bluetoothOk = bluetooth.begin();
  motors.emergencyStop();
  delay(30);
  serialProtocol.sendLine("READY,AI_ROBOT_ROVER");
  if (!bluetoothOk) serialProtocol.sendError("BLUETOOTH_INIT_FAILED");
  if (!sensors.readings().lightHealthy) serialProtocol.sendError("BH1750_INIT_FAILED");
}

void loop() {
  ParsedCommand command;
  while (serialProtocol.poll(command)) {
    serialTimedOut = false;
    handleCommand(command);
  }
  while (bluetooth.poll(command)) handleCommand(command);

  ultrasonics.update();
  sensors.update();
  const auto& sensorData = sensors.readings();
  leds.setDark(sensorData.lightHealthy && isfinite(sensorData.lightLux) &&
               sensorData.lightLux < Config::DARK_THRESHOLD_LUX);
  if (sensors.consumeClapEvent()) {
    leds.setUserEnabled(!leds.userEnabled());
    serialProtocol.sendLine("EVENT,CLAP,LED_TOGGLED");
  }

  if (ultrasonics.emergencyObstacle()) latchEmergency("ULTRASONIC");
  leds.setObstacle(ultrasonics.closeObstacle());
  const bool sensorFault = ultrasonics.sensorFault();
  leds.setError(sensorFault || !sensorData.lightHealthy);
  if (sensorFault && !sensorFaultWasActive) serialProtocol.sendError("SENSOR_TIMEOUT");
  if (!sensorFault && sensorFaultWasActive) serialProtocol.sendLine("EVENT,SENSORS_RECOVERED");
  sensorFaultWasActive = sensorFault;

  const uint32_t now = millis();
  const bool serialLinkLost = serialProtocol.lastReceiveMs() != 0 &&
                              now - serialProtocol.lastReceiveMs() > Config::SERIAL_LINK_TIMEOUT_MS;
  if (serialLinkLost && currentMode != RobotMode::BLUETOOTH && !serialTimedOut) {
    motors.stopAll(true);
    autonomous.stop();
    serialTimedOut = true;
    if (currentMode != RobotMode::MANUAL) changeMode(RobotMode::MANUAL, CommandSource::SERIAL_LINK);
    serialProtocol.sendError("SERIAL_LINK_TIMEOUT");
  }

  if (!emergencyLatched && !serialTimedOut && currentMode == RobotMode::AUTONOMOUS) {
    autonomous.update(ultrasonics.readings());
  }

  if (!emergencyLatched && motors.isMoving() &&
      currentMode != RobotMode::AUTONOMOUS &&
      now - lastMotionCommandMs > Config::COMMAND_TIMEOUT_MS) {
    motors.stopAll(true);
    serialProtocol.sendLine("EVENT,COMMAND_TIMEOUT,STOPPED");
  }

  const bool btConnected = bluetooth.connected();
  if (bluetoothWasConnected && !btConnected && currentMode == RobotMode::BLUETOOTH) {
    motors.stopAll(true);
    serialProtocol.sendLine("BLUETOOTH,DISCONNECTED");
  } else if (!bluetoothWasConnected && btConnected) {
    serialProtocol.sendLine("BLUETOOTH,CONNECTED");
  }
  bluetoothWasConnected = btConnected;
  if (currentMode == RobotMode::BLUETOOTH && motors.isMoving() &&
      now - bluetooth.lastReceiveMs() > Config::BLUETOOTH_LINK_TIMEOUT_MS) {
    motors.stopAll(true);
    bluetooth.sendLine("EVENT,COMMAND_TIMEOUT,STOPPED");
  }

  if (now - lastTelemetryMs >= Config::TELEMETRY_INTERVAL_MS) {
    lastTelemetryMs = now;
    publishTelemetry();
  }
  if (now - lastStatusMs >= Config::STATUS_INTERVAL_MS) {
    lastStatusMs = now;
    publishStatus();
  }
  leds.setConnected(btConnected || now - serialProtocol.lastReceiveMs() < Config::SERIAL_LINK_TIMEOUT_MS);
  motors.update();
  leds.update();
  yield();
}

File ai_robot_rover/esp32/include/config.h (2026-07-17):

#pragma once

#include <Arduino.h>

namespace Config {

// IMPORTANT : valeurs de reference pour ESP32 DevKit V1. Verifier le cablage
// avant d'alimenter. Les ECHO HC-SR04 (5 V) exigent des diviseurs vers 3,3 V.
constexpr uint32_t SERIAL_BAUD = 115200;
constexpr char BLUETOOTH_NAME[] = "AI-Robot-Rover";

// Deux TB6612FNG. Relier physiquement les deux broches STBY ensemble.
constexpr uint8_t MOTOR_STBY_PIN = 4;
constexpr uint8_t FL_IN1_PIN = 13;
constexpr uint8_t FL_IN2_PIN = 14;
constexpr uint8_t FL_PWM_PIN = 25;
constexpr uint8_t RL_IN1_PIN = 26;
constexpr uint8_t RL_IN2_PIN = 27;
constexpr uint8_t RL_PWM_PIN = 33;
constexpr uint8_t FR_IN1_PIN = 16;
constexpr uint8_t FR_IN2_PIN = 17;
constexpr uint8_t FR_PWM_PIN = 18;
constexpr uint8_t RR_IN1_PIN = 19;
constexpr uint8_t RR_IN2_PIN = 23;
constexpr uint8_t RR_PWM_PIN = 5;

constexpr bool FL_INVERTED = false;
constexpr bool RL_INVERTED = false;
constexpr bool FR_INVERTED = true;
constexpr bool RR_INVERTED = true;

constexpr uint8_t PWM_CHANNEL_FL = 0;
constexpr uint8_t PWM_CHANNEL_RL = 1;
constexpr uint8_t PWM_CHANNEL_FR = 2;
constexpr uint8_t PWM_CHANNEL_RR = 3;
constexpr uint32_t PWM_FREQUENCY = 18000;
constexpr uint8_t PWM_RESOLUTION_BITS = 8;
constexpr uint8_t MAX_SPEED = 210;
constexpr uint8_t DEFAULT_SPEED = 130;
constexpr uint8_t MIN_TEST_SPEED = 55;
constexpr uint8_t AUTONOMOUS_SPEED = 125;
constexpr uint8_t TURN_SPEED = 115;
constexpr uint8_t REVERSE_SPEED = 95;
constexpr uint8_t ACCEL_STEP = 6;
constexpr uint8_t DECEL_STEP = 10;
constexpr uint32_t MOTOR_RAMP_INTERVAL_MS = 20;
constexpr uint32_t COMMAND_TIMEOUT_MS = 700;
constexpr uint32_t SERIAL_LINK_TIMEOUT_MS = 2500;
constexpr uint32_t BLUETOOTH_LINK_TIMEOUT_MS = 1200;

// GPIO 2, 12 et 15 sont des broches de strapping sur de nombreuses cartes.
// Les TRIG ne doivent jamais les tirer au niveau oppose pendant le demarrage.
constexpr uint8_t US_LEFT_TRIG_PIN = 2;
constexpr uint8_t US_LEFT_ECHO_PIN = 34;
constexpr uint8_t US_CENTER_TRIG_PIN = 15;
constexpr uint8_t US_CENTER_ECHO_PIN = 35;
constexpr uint8_t US_RIGHT_TRIG_PIN = 12;
constexpr uint8_t US_RIGHT_ECHO_PIN = 39;
constexpr uint32_t ULTRASONIC_TIMEOUT_US = 24000;
constexpr uint32_t ULTRASONIC_SENSOR_SPACING_MS = 35;
constexpr uint8_t ULTRASONIC_MEDIAN_SAMPLES = 5;
constexpr float ULTRASONIC_MIN_VALID_CM = 2.0F;
constexpr float ULTRASONIC_MAX_VALID_CM = 400.0F;
constexpr float SLOW_DISTANCE_CM = 55.0F;
constexpr float MIN_DISTANCE_CM = 28.0F;
constexpr float EMERGENCY_DISTANCE_CM = 12.0F;
constexpr uint8_t SENSOR_MAX_CONSECUTIVE_FAILURES = 8;

constexpr uint8_t I2C_SDA_PIN = 21;
constexpr uint8_t I2C_SCL_PIN = 22;
constexpr uint8_t BH1750_ADDRESS = 0x23;
constexpr uint32_t LIGHT_READ_INTERVAL_MS = 300;
constexpr float DARK_THRESHOLD_LUX = 35.0F;

constexpr uint8_t SOUND_ADC_PIN = 36;
constexpr uint16_t SOUND_STRONG_THRESHOLD = 2850;
constexpr float SOUND_FILTER_ALPHA = 0.12F;
constexpr uint32_t SOUND_SAMPLE_INTERVAL_MS = 5;
constexpr uint32_t CLAP_DEBOUNCE_MS = 900;

// Bande ou anneau WS2812 : plusieurs LEDs pilotees avec une seule broche.
constexpr uint8_t LED_DATA_PIN = 32;
constexpr uint16_t LED_COUNT = 4;
constexpr uint8_t LED_BRIGHTNESS = 60;
constexpr uint32_t LED_BLINK_INTERVAL_MS = 350;

constexpr uint32_t TELEMETRY_INTERVAL_MS = 250;
constexpr uint32_t STATUS_INTERVAL_MS = 1000;
constexpr uint32_t AUTONOMOUS_REVERSE_MS = 550;
constexpr uint32_t AUTONOMOUS_TURN_MS = 650;
constexpr uint32_t AUTONOMOUS_STUCK_TIMEOUT_MS = 7000;
constexpr uint8_t MAX_COMMAND_LENGTH = 96;

}  // namespace Config

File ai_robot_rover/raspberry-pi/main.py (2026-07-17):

#!/usr/bin/env python3
"""Point d'entree du robot. Un STOP est envoye au demarrage et a la fermeture."""

from __future__ import annotations

import signal
import sys

from logger import log
from robot_controller import RobotController
from web_server import WebServer


def main() -> int:
    robot = RobotController()
    server = WebServer(robot)
    stopping = False

    def request_stop(signum, _frame) -> None:
        nonlocal stopping
        if stopping:
            return
        stopping = True
        log.warning("Signal %s recu: STOP et fermeture", signum)
        robot.shutdown()
        raise KeyboardInterrupt

    signal.signal(signal.SIGTERM, request_stop)
    signal.signal(signal.SIGINT, request_stop)
    try:
        robot.start()
        robot.stop(urgent=True)
        server.run()
    except KeyboardInterrupt:
        pass
    except Exception:
        log.exception("Crash du programme principal")
        robot.emergency_stop("crash Raspberry Pi")
        return 1
    finally:
        if not stopping:
            robot.shutdown()
    return 0


if __name__ == "__main__":
    sys.exit(main())

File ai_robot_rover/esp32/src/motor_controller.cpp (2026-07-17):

#include "motor_controller.h"

#include <algorithm>

void MotorController::begin() {
  pinMode(Config::MOTOR_STBY_PIN, OUTPUT);
  digitalWrite(Config::MOTOR_STBY_PIN, LOW);
  for (auto& motor : motors_) {
    pinMode(motor.in1, OUTPUT);
    pinMode(motor.in2, OUTPUT);
    digitalWrite(motor.in1, LOW);
    digitalWrite(motor.in2, LOW);
    ledcSetup(motor.pwmChannel, Config::PWM_FREQUENCY, Config::PWM_RESOLUTION_BITS);
    ledcAttachPin(motor.pwmPin, motor.pwmChannel);
    ledcWrite(motor.pwmChannel, 0);
  }
  stopAll(true);
}

int16_t MotorController::clampSpeed(int16_t value) {
  return constrain(value, -static_cast<int16_t>(Config::MAX_SPEED),
                   static_cast<int16_t>(Config::MAX_SPEED));
}

void MotorController::setMotorTargets(int16_t frontLeft, int16_t rearLeft,
                                      int16_t frontRight, int16_t rearRight) {
  motors_[0].target = clampSpeed(frontLeft);
  motors_[1].target = clampSpeed(rearLeft);
  motors_[2].target = clampSpeed(frontRight);
  motors_[3].target = clampSpeed(rearRight);
  commandedSpeed_ = max(max(abs(motors_[0].target), abs(motors_[1].target)),
                        max(abs(motors_[2].target), abs(motors_[3].target)));
  if (commandedSpeed_ > 0) digitalWrite(Config::MOTOR_STBY_PIN, HIGH);
}

void MotorController::setMotion(MotionAction action, uint8_t requestedSpeed) {
  const int16_t speed = min(requestedSpeed, Config::MAX_SPEED);
  const int16_t inner = speed * 45 / 100;
  switch (action) {
    case MotionAction::FORWARD: setMotorTargets(speed, speed, speed, speed); break;
    case MotionAction::BACKWARD: setMotorTargets(-speed, -speed, -speed, -speed); break;
    case MotionAction::TURN_LEFT: setMotorTargets(inner, inner, speed, speed); break;
    case MotionAction::TURN_RIGHT: setMotorTargets(speed, speed, inner, inner); break;
    case MotionAction::ROTATE_LEFT: setMotorTargets(-speed, -speed, speed, speed); break;
    case MotionAction::ROTATE_RIGHT: setMotorTargets(speed, speed, -speed, -speed); break;
    default: stopAll(); break;
  }
}

int16_t MotorController::rampValue(int16_t current, int16_t target) {
  if (current == target) return current;
  if ((current > 0 && target < 0) || (current < 0 && target > 0)) target = 0;
  const uint8_t step = abs(target) > abs(current) ? Config::ACCEL_STEP : Config::DECEL_STEP;
  if (current < target) return std::min<int16_t>(current + step, target);
  return std::max<int16_t>(current - step, target);
}

void MotorController::writeMotor(Motor& motor) {
  int16_t effective = motor.inverted ? -motor.current : motor.current;
  if (effective > 0) {
    digitalWrite(motor.in1, HIGH);
    digitalWrite(motor.in2, LOW);
  } else if (effective < 0) {
    digitalWrite(motor.in1, LOW);
    digitalWrite(motor.in2, HIGH);
  } else {
    digitalWrite(motor.in1, LOW);
    digitalWrite(motor.in2, LOW);
  }
  ledcWrite(motor.pwmChannel, abs(effective));
}

void MotorController::update() {
  const uint32_t now = millis();
  if (now - lastRampMs_ < Config::MOTOR_RAMP_INTERVAL_MS) return;
  lastRampMs_ = now;
  bool active = false;
  for (auto& motor : motors_) {
    motor.current = rampValue(motor.current, motor.target);
    writeMotor(motor);
    active = active || motor.current != 0 || motor.target != 0;
  }
  digitalWrite(Config::MOTOR_STBY_PIN, active ? HIGH : LOW);
}

void MotorController::stopAll(bool immediate) {
  commandedSpeed_ = 0;
  for (auto& motor : motors_) {
    motor.target = 0;
    if (immediate) {
      motor.current = 0;
      writeMotor(motor);
    }
  }
  if (immediate) digitalWrite(Config::MOTOR_STBY_PIN, LOW);
}

void MotorController::emergencyStop() { stopAll(true); }

bool MotorController::isMoving() const {
  for (const auto& motor : motors_) {
    if (motor.current != 0 || motor.target != 0) return true;
  }
  return false;
}

uint8_t MotorController::commandedSpeed() const { return commandedSpeed_; }
